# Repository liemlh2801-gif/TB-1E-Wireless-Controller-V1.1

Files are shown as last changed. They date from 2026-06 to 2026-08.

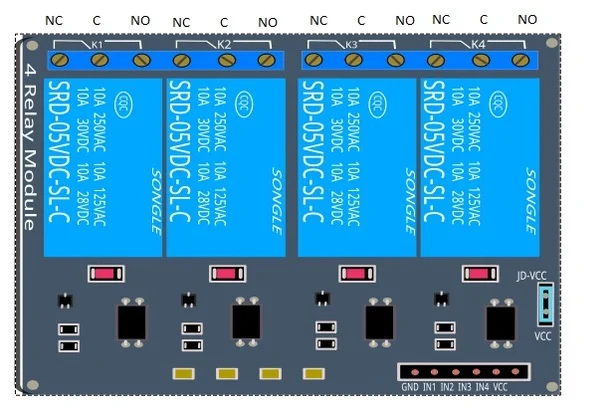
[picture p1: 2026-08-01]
hardware/qelectrotech/elements/Relay-module-for-arduino-616x415.webp

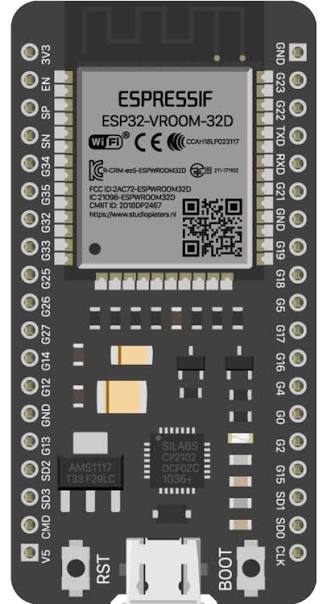
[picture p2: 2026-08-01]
hardware/qelectrotech/elements/images.jpg

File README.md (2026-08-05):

# ESP32 Bluetooth Controller

Android app + **iOS app** + **web app** + ESP32 firmware for controlling a motor/actuator with **UP**, **STOP**, and **DOWN** commands over Bluetooth.

No HC-05 module required — Bluetooth is built into the ESP32.

**Recommended project path (ASCII only, for Gradle/Fritzing on Windows):**

`D:\01 Lam viec\Gia-cong\drawings\safety-belt-tester\APP\arduino-bt-controller`

## Hardware

### Which ESP32 board?

| Board in Arduino IDE | Chip | Bluetooth | App connection |
|---|---|---|---|
| **ESP32 Dev Module** | WROOM-32 | **BLE** (NUS) | Android, **Chrome web**, pair via app/browser |
| **ESP32S3 Dev Module** | S3 | BLE only | Same as WROOM |
| ESP32-C3 / C6 | C3 / C6 | BLE only | Same as S3 |

**Important:** If you see `BluetoothSerial.h: No such file`, you selected **ESP32-S3** (or C3/C6). That is normal — the sketch now uses **BLE** on those boards automatically. Keep your **ESP32S3 Dev Module** board selected and upload again.

### Wiring — ESP32 to L298N

| ESP32 GPIO | L298N / function |
|---|---|
| **3.3V or 5V** | VCC (logic; module power separate) |
| **GND** | GND |
| **GPIO 26** | IN1 |
| **GPIO 27** | IN2 |
| **GPIO 14** | Stop signal |
| **GPIO 25** | BLE connected (idle HIGH; LOW while phone/PC is connected) |
| **GPIO 32** | Manual / Auto mode switch (see below) |
| **GPIO 18** | Top limit switch (see below) |
| **GPIO 19** | Bottom limit switch (see below) |
| **GPIO 33** | ON-HOLD switch (see below) |

| Command | GPIO 26 (IN1) | GPIO 27 (IN2) | GPIO 14 (STOP) |
|---|---|---|---|
| UP | LOW | HIGH | HIGH |
| DOWN | HIGH | LOW | HIGH |
| STOP | HIGH | HIGH | **LOW** |
| RELEASE / idle | HIGH | HIGH | HIGH |

### Manual / Auto mode switch (GPIO 32)

Physical **Manual / Auto** selector on the machine panel. ESP32 reads **GPIO 32** with internal pull-down (Manual is default):

| Switch position | GPIO 32 | Mode | App behavior |
|---|---|---|---|
| **Manual** (default) | **Open** or **GND** | Manual | Momentary — hold LÊN/DỪNG/XUỐNG, release sends `RELEASE` |
| **Auto** | **3.3V only** | Auto | Latch — press/release LÊN or XUỐNG keeps output until DỪNG, opposite direction, or limit |

**Wiring:**

- **Manual:** leave GPIO 32 **open**, or connect to **GND**
- **Auto:** connect GPIO 32 to **3.3V** only (do not use open/float for Auto)

On mode change or BLE connect, ESP32 notifies the app with `MODE: MANUAL` or `MODE: AUTO`.

### App buttons (web / Android / iOS)

App / web buttons match the physical panel (GPIO 21 / 22 / 23). The ESP32 applies the same rules to BLE commands via `maintainAppPanelButtons()` (Manual: hold to run; Auto: latch on press; DỪNG priority). Physical panel inputs take priority if pressed at the same time.

**Manual** (GPIO 32 open or GND):

| Button | Press | Release |
|---|---|---|
| **LÊN** | `UP` — GPIO 26 LOW, GPIO 27/14 HIGH | `RELEASE` — all HIGH |
| **DỪNG** | `STOP` — GPIO 14 LOW | `RELEASE` — all HIGH |
| **XUỐNG** | `DOWN` — GPIO 27 LOW, GPIO 26/14 HIGH | `RELEASE` — all HIGH |

Priority while held: **DỪNG** > **LÊN** > **XUỐNG** (same as panel).

**Auto** (GPIO 32 on 3.3V):

| Button | Press | Release |
|---|---|---|
| **LÊN** | `UP` — GPIO 26 LOW, GPIO 27/14 HIGH | No change — latched |
| **DỪNG** | `STOP` — GPIO 14 LOW | `RELEASE` — all HIGH |
| **XUỐNG** | `DOWN` — GPIO 27 LOW, GPIO 26/14 HIGH | No change — latched |

While **DỪNG** is held, **LÊN** / **XUỐNG** are ignored (same as panel).

### Limit switches (GPIO 18 / GPIO 19)

Two **normally-open** limit switches. ESP32 reads **GPIO 18** (top) and **GPIO 19** (bottom) with internal pull-up:

| Switch | GPIO | Active (limit hit) | Inactive (normal) |
|---|---|---|---|
| **Top limit** | **18** | **LOW** (pin to **GND**) | **Open** or **HIGH** |
| **Bottom limit** | **19** | **LOW** (pin to **GND**) | **Open** or **HIGH** |

**While top limit active:** GPIO 26 set HIGH, then disabled (cannot go LOW); GPIO 27 and GPIO 14 unchanged.

**While bottom limit active:** GPIO 27 set HIGH, then disabled (cannot go LOW); GPIO 26 and GPIO 14 unchanged.

**Wiring (each limit switch):**

- One terminal → **GPIO 18** (top) or **GPIO 19** (bottom)
- Other terminal → **GND**
- Switch closes to GND when the carriage hits the limit (NO switch)

When top limit clears, GPIO 26 is enabled again; if **GPIO 21** is still connected to **GND**, GPIO 26 is allowed to go **LOW**.

When bottom limit clears, GPIO 27 is enabled again; if **GPIO 22** is still connected to **GND**, GPIO 27 is allowed to go **LOW**.

On limit change or BLE connect, ESP32 sends `LIMIT: TOP`, `LIMIT: TOP OFF`, `LIMIT: BOT`, or `LIMIT: BOT OFF`.

### ON-HOLD switch (GPIO 33)

ESP32 reads **GPIO 33** with internal pull-up:

| Switch | GPIO 33 | Effect |
|---|---|---|
| **ON-HOLD active** | **LOW** (pin to **GND**) | **UP input and output stay enabled**; AUTO-DOWN latch cleared |
| **Inactive** | **Open** or **HIGH** | Normal operation |
| **ON-HOLD release** (active→inactive) | LOW→open | If ON-HOLD stays **inactive for 3 seconds**: GPIO 26 inactive (HIGH), GPIO 27 **GND** (LOW), GPIO 14 inactive (HIGH) — same as panel XUỐNG press-release once in Auto (if GPIO 4 enabled). Count resets if ON-HOLD goes active again. |

**Wiring:** one terminal → **GPIO 33**, other → **GND** (closes to GND when hold is engaged).

Panel **LÊN** (GPIO 21), app **UP**, and GPIO 26 output are **never disabled** while ON-HOLD is active.

Device advertises as **TB-1E** when powered on.

## Protocol

Commands are newline-terminated ASCII strings:

| Button | Sent |
|---|---|
| UP | `UP` |
| STOP | `STOP` |
| DOWN | `DOWN` |

Mode notifications from ESP32:

| Message | Meaning |
|---|---|
| `MODE: MANUAL` | Manual mode — momentary buttons |
| `MODE: AUTO` | Auto mode — UP/DOWN latch after release |
| `LIMIT: TOP` / `LIMIT: TOP OFF` | Top limit active / cleared |
| `LIMIT: BOT` / `LIMIT: BOT OFF` | Bottom limit active / cleared |

ESP32 replies with `STATUS: UP`, `STATUS: DOWN`, or `STATUS: STOP`.

## Setup

### 1. ESP32 firmware

1. Install [ESP32 board support](https://docs.espressif.com/projects/arduino-esp32/en/latest/installing.html) in Arduino IDE.
2. Open `esp32/bt_controller/bt_controller.ino`.
3. Select the board that matches your hardware:
   - **ESP32 Dev Module** — original ESP32 (WROOM-32)
   - **ESP32S3 Dev Module** — ESP32-S3 (most common new boards)
4. Select the correct **COM port** (CP2102 / CH340 USB driver if needed).
5. Upload the sketch.
6. Serial Monitor **115200 baud** — you should see:
   - `Bluetooth: BLE UART (TB-1E)`
   - `Bluetooth name: TB-1E`

### 2. Android app (v1.3+)

1. Install **app-debug.apk** (yellow bar shows **v1.3**).
2. Grant **Bluetooth** and **Location** permissions.
3. Power on ESP32.
4. In app **⋮** menu → **refresh** (waits ~5 s for BLE scan).
5. Select **TB-1E** → **KẾT NỐI MÁY THỬ DÂY AN TOÀN**.
6. Use **LÊN**, **DỪNG**, **XUỐNG**.

**WROOM-32 / S3:** connect from the app or Chrome — do not rely on Windows Settings pairing alone.

### 3. iOS app (v1.0)

Requires **ESP32 BLE** firmware (WROOM-32 or S3/C3/C6).

1. On a Mac, open `ios/TB1EController.xcodeproj` in Xcode.
2. Set your **Signing Team** and run on your iPhone.
3. See [ios/README.md](ios/README.md) for full steps.

### 4. Web app (Chrome PC + Chrome Android)

Browser controller in `web/` — no install, **Web Bluetooth** (same protocol as Android app).

1. ESP32 with BLE firmware (WROOM-32 or S3/C3/C6), name **TB-1E**
2. Open **GitHub Pages** URL in **Chrome or Edge on PC**, or Chrome on Android — see [web/README.md](web/README.md)
3. **KẾT NỐI** → hold **LÊN / DỪNG / XUỐNG** (mouse/touch) or **↑ ↓ Space** on PC keyboard

**Safari iPhone:** Web Bluetooth not supported — use the iOS app instead.

### 5. Compile errors

| Error | Cause | Fix |
|---|---|-----|
| `BluetoothSerial.h: No such file` | Old sketch on S3 board | Use latest sketch — it switches to BLE on S3 |
| `#error Select original ESP32` | Old sketch | Update sketch from this repo |
| Upload fails | USB driver / boot mode | Hold **BOOT** during upload; install CP2102/CH340 driver |

## Troubleshooting

| Problem | Fix |
|---|-----|
| **TB-1E** not in app menu | Power ESP32; tap **refresh** in app (BLE scan ~5 s) |
| App connect fails (WROOM-32) | Settings → **TB-1E** → **Disconnect**; connect only from app |
| App connect fails (S3) | Install app **v1.3+**; refresh; select scanned **TB-1E** |
| Motor not moving | Check GPIO 26/27/14 wiring to L298N |

## Project structure

```
arduino-bt-controller/
├── android/          # Kotlin app (Classic BT + BLE)
├── ios/              # SwiftUI iPhone app (BLE only)
├── web/              # Browser app (Web Bluetooth, Chrome Android)
├── esp32/            # ESP32 firmware
├── arduino/          # Legacy note (Nano + HC-05 removed)
└── README.md
```

## Safety

- App sends **RELEASE** on button release, disconnect, and when paused.
- ESP32 sets all GPIO **HIGH** when no app is connected.

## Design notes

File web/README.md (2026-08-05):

# TB-1E Web Controller

Browser version of the TB-1E controller. Same UI and protocol as the Android app.

Works over **Web Bluetooth (BLE)** — connect to ESP32 **TB-1E**. Button behavior matches the physical panel (Manual / Auto).

## Browser support

| Browser | Works? | Notes |
|---|---|---|
| **Chrome on PC (Windows/macOS/Linux)** | **Yes** | Same as Android app — connect **TB-1E**, mouse or keyboard |
| **Edge on PC** | **Yes** | Web Bluetooth supported |
| **Chrome on Android** | **Yes** | Touch controls |
| **Safari on iPhone** | **No** | Use iOS app or Bluefy |
| Firefox | No | Use Chrome or Edge |

**PC (Chrome):** open the GitHub Pages URL → **KẾT NỐI** → pick **TB-1E**. Hold **LÊN / DỪNG / XUỐNG** with mouse, or keys **↑ ↓ Space** (release sends `RELEASE`).

**Hardware:** ESP32-WROOM-32 or ESP32-S3/C3/C6 with BLE firmware.

## Deploy on GitHub Pages (PC Chrome or phone)

After pushing to `main`:

1. Repo → **Settings** → **Pages** → Source: **GitHub Actions**
2. Push triggers `.github/workflows/deploy-web.yml`
3. Open the Pages URL (HTTPS), e.g.:

   `https://liemlh2801-gif.github.io/TB-1E-Wireless-Controller-V1.1/`

4. **PC:** Chrome or Edge → **KẾT NỐI** → **TB-1E** → use buttons or **↑ ↓ Space**
5. **Android:** Chrome → **KẾT NỐI** → hold touch buttons

Safari on iPhone cannot use Web Bluetooth — use the iOS app.

## HTTPS required

Web Bluetooth only runs on **secure pages** (`https://` or `http://localhost`).

Opening `http://192.168.x.x:8080` from your phone **will not work**.

### Option A — PC Chrome (GitHub Pages or localhost)

1. Deploy `web/` to GitHub Pages (HTTPS), or run locally:

```powershell
cd web
npx --yes serve -l 3000
```

2. Open **`http://localhost:3000`** in **Chrome** or **Edge** on the same PC.
3. Turn on **Bluetooth** (Windows Settings → Bluetooth).
4. Power on ESP32 **TB-1E** (BLE firmware).
5. Click **KẾT NỐI MÁY THỬ DÂY AN TOÀN** → select **TB-1E**.
6. Control: click/hold **LÊN / DỪNG / XUỐNG**, or keyboard **↑ ↓ Space** (release = `RELEASE`).

### Option B — Quick UI test on PC (no BLE over plain HTTP)

```bash
cd web
npx --yes serve -l 3000
```

Open `http://localhost:3000` — UI only; Web Bluetooth needs **HTTPS** or **localhost** (localhost works in Chrome on PC).

### Option C — Phone on same Wi‑Fi (HTTPS)

1. Install [mkcert](https://github.com/FiloSottile/mkcert) (once).
2. From the `web` folder run:

```powershell
.\serve-https.ps1
```

3. On your phone (Chrome), open `https://<your-PC-IP>:8443`
4. Accept the certificate warning (self-signed).
5. Tap **KẾT NỐI** → choose **TB-1E**.

### Option D — Deploy to HTTPS hosting

Upload the `web/` folder to any static host with HTTPS (GitHub Pages, Netlify, etc.) and open the URL on your phone.

## Panel image

If the machine image is missing:

```bash
cp ../android/app/src/main/res/drawable/asset1.jpg web/assets/asset1.jpg
```

## Protocol

App / web buttons match the physical panel in **Manual** and **Auto** mode (including DỪNG priority over LÊN / XUỐNG).

**Manual:** `UP` / `DOWN` / `STOP` on press, `RELEASE` on release.

**Auto:**

| Button | Press | Release |
|---|---|---|
| LÊN | `UP` — GPIO 26 LOW | No command |
| DỪNG | `STOP` — GPIO 14 LOW | `RELEASE` — all HIGH |
| XUỐNG | `DOWN` — GPIO 27 LOW | No command |

ESP32 sends `MODE: MANUAL` or `MODE: AUTO` on connect and when the physical mode switch changes.

BLE service: Nordic UART `6E400001-B5A3-F393-E0A9-E50E24DCCA9E`

## Files

```
web/
├── index.html
├── manifest.json
├── css/styles.css
├── js/bluetooth.js
├── js/app.js
├── assets/asset1.jpg
├── serve-https.ps1
└── README.md
```

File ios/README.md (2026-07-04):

# TB-1E Controller — iOS

SwiftUI iPhone app for controlling the **MAY THU DAY AN TOAN (TB-1E)** machine over **Bluetooth LE**.

Matches the Android app: **LÊN / DỪNG / XUỐNG** momentary buttons, connect to **TB-1E**, same command protocol (`UP`, `STOP`, `DOWN`, `RELEASE`).

## Important: iOS and Bluetooth type

| Platform | Classic Bluetooth (ESP32-WROOM SPP) | BLE (ESP32-S3 / C3 / C6) |
|---|---|---|
| Android  | Yes | Yes |
| **iOS**  | **No** (Apple restriction) | **Yes** |

Use **ESP32-S3** firmware from `esp32/bt_controller/bt_controller.ino` with board **ESP32S3 Dev Module**.

## Requirements

- Mac with **Xcode 15+**
- iPhone with **iOS 16+**
- Apple Developer account (free tier works for device testing)
- ESP32-S3 running TB-1E BLE firmware

## Setup in Xcode

1. Open `ios/TB1EController.xcodeproj` in Xcode.
2. Target **TB1EController** → **Signing & Capabilities** → select your **Team**.
3. Connect iPhone → **Run** (▶).
4. Allow **Bluetooth** when prompted.

### Machine panel image

If the machine image is missing:

```bash
cp android/app/src/main/res/drawable/asset1.jpg \
   ios/TB1EController/Assets.xcassets/asset1.imageset/asset1.jpg
```

## Using the app

1. Power on ESP32 (**TB-1E**).
2. Tap **⋯** → **Refresh devices** (~5 s scan).
3. Select **TB-1E**.
4. Tap **KẾT NỐI MÁY THỬ DÂY AN TOÀN**.
5. **Hold** **LÊN / DỪNG / XUỐNG** — release sends `RELEASE`.

## Protocol

| Action | Command |
|---|---|
| LÊN pressed | `UP` |
| XUỐNG pressed  | `DOWN` |
| DỪNG pressed | `STOP` |
| Button release | `RELEASE` |

ESP32 sends `MODE: MANUAL` or `MODE: AUTO` from the physical mode switch (GPIO 32). In **Auto** mode, wireless buttons are disabled.

BLE: Nordic UART `6E400001-B5A3-F393-E0A9-E50E24DCCA9E`

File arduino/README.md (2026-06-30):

# Legacy Arduino Nano + HC-05

This project now uses **ESP32** built-in Bluetooth instead of Arduino Nano + HC-05.

Use the firmware in [`../esp32/bt_controller/`](../esp32/bt_controller/).

The old `bt_controller.ino` for Nano/HC-05 has been removed.

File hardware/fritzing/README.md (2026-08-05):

# TB-1E — Fritzing wiring (ESP32 38-pin + CW-022)

Realistic breadboard wiring diagram for **TB-1E** using **Fritzing 0.9.3** at:

```
E:\fritzing.0.9.3b.64.pc\Fritzing.exe
```

## ESP32 part (import first)

This sketch uses the **ESP32 DevKitc V4** part from your **Mine** parts bin (not the broken embedded TB1E part).

1. In Fritzing: **File → Open** → `C:\Users\Admin\Downloads\ESP32 DevKitc V4.fzpz`  
   (or **Mine → Import** if already imported once)
2. Then open the wiring sketch via `open_in_fritzing.bat`

| Wire | ESP32 DevKitc V4 pin | CW-022 |
|---|---|---|
| Red | **5V** | VCC |
| Black | **GND** | GND |
| Blue | **IO26** | IN1 |
| Blue | **IO27** | IN2 |
| Green | **IO14** | IN3 |

> **Note:** You imported `ESP32 DevKitc V4.fzpz` (in Downloads), not `ESP32-38PinWide-fixed.fzpz` from the Fritzing forum. Both are 38-pin ESP32 boards; DevKitc V4 has a photo-realistic breadboard view and is valid for TB-1E wiring.

## Quick start

1. **Generate** (if `TB-1E_ESP32_CW022_Wiring.fzz` is missing):
   ```
   python hardware/fritzing/generate_tb1e_fritzing.py
   ```

2. **Open** — double-click:
   ```
   hardware/fritzing/open_in_fritzing.bat
   ```
   Or in Fritzing: **File → Open** → `C:\TB1E_Fritzing\TB-1E_ESP32_CW022_Wiring.fzz`

   **Important:** Fritzing 0.9.3 on Windows cannot open `.fzz` files from paths with Vietnamese/Unicode characters. Keep the project under ASCII-only folders:

   `D:\01 Lam viec\Gia-cong\drawings\safety-belt-tester\APP\arduino-bt-controller`

   Or use the batch file / copy under `C:\TB1E_Fritzing\`.

3. Switch to **Breadboard** view for the physical wiring layout.

## What's in the sketch

| Part | Pins shown |
|---|---|
| **ESP32 DevKitc V4** | Imported user part — 38 pins (IO26, IO27, IO14, 5V, GND, …) |
| **CW-022 4CH relay** | GND, IN1, IN2, IN3, IN4, VCC |

### Pre-wired (motor outputs)

| Wire color | ESP32 | CW-022 | Function |
|---|---|---|---|
| Red | 5V | VCC | 5V power |
| Black | GND | GND | Ground |
| Blue | IO26 | IN1 | Motor IN1 (LÊN) |
| Blue | IO27 | IN2 | Motor IN2 (XUỐNG) |
| Green | IO14 | IN3 | STOP (DỪNG) |
| — | — | IN4 | Spare |

**CW-022 is active LOW:** GPIO HIGH = relay off, GPIO LOW = relay on.

## Add panel wiring in Fritzing

Drag wires from these ESP32 pins to switches/buttons (switch other terminal → **GND**):

| GPIO | Function |
|---|---|
| 32 | Manual / Auto |
| 18 | Top limit |
| 19 | Bottom limit |
| 25 | ON-HOLD |
| 21 | Panel LÊN |
| 22 | Panel XUỐNG |
| 23 | Panel DỪNG |
| 4 | AUTO-DOWN |
| 33 | BLE connected output (LOW = connected) |

## Custom parts

- `parts/TB1E_CW022_4ch/` — CW-022 4-channel relay (embedded in `.fzz`)
- ESP32: use imported **ESP32 DevKitc V4** (see above). Legacy `TB1E_ESP32_38pin/` is no longer used by the sketch.

## Optional: ESP32-38PinWide-fixed (forum)

If you prefer Peter van Epp's forum part instead of DevKitc V4, download `ESP32-38PinWide-fixed.fzpz` from the [Fritzing forum](https://forum.fritzing.org/t/esp32-wroom-32u/12978), import it, then reconnect wires manually in the sketch.

## Regenerate

```
python hardware/fritzing/generate_tb1e_fritzing.py
```

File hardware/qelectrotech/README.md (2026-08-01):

# TB-1E — ESP32 ↔ CW-022 Wiring (QElectroTech)

Wiring sketch for **ESP32 Dev Module** connected to **CW-022** 2-channel 5V relay modules, for the TB-1E wireless controller firmware.

## Open in QElectroTech

1. Install [QElectroTech](https://qelectrotech.org/) (0.8 or newer recommended).
2. Open file:
   ```
   hardware/qelectrotech/TB-1E_ESP32_CW022_Wiring.qet
   ```
3. Three folios (tabs):
   - **F1 — ESP32 to CW-022 Control** — main control wiring
   - **F2 — CW-022 Relay Outputs** — relay contacts to machine
   - **F3 — Panel Inputs Reference** — switches and buttons

Custom symbols are embedded in the project (`tb1e` collection). Standalone copies are in `elements/`.

## CW-022 module

Standard **2-channel 5V opto-isolated relay board** (often labeled CW-022 / 2CH relay):

| Pin | Connect to |
|-----|---|
| **VCC** | ESP32 **5V** (VIN / USB 5V) |
| **GND** | ESP32 **GND** (common ground) |
| **IN1** | ESP32 GPIO (see table) |
| **IN2** | ESP32 GPIO (see table) |
| **JD-VCC** | Jumper **ON** (default) — shares 5V with VCC |

**Trigger:** Active **LOW** — GPIO **LOW** = relay ON, GPIO **HIGH** = relay OFF.

TB-1E firmware needs **3 relay channels** → use **2× CW-022** modules.

## Control wiring (Folio 1)

| ESP32 | CW-022 module | Channel | Function |
|---|---|---|---|
| **5V** | #1 VCC, #2 VCC | — | Logic + coil power |
| **GND** | #1 GND, #2 GND | — | Common ground |
| **GPIO 26** | #1 **IN1** | R1 | Motor IN1 (LÊN) |
| **GPIO 27** | #1 **IN2** | R2 | Motor IN2 (XUỐNG) |
| **GPIO 14** | #2 **IN1** | R1 | Motor STOP (DỪNG) |
| — | #2 IN2 | R2 | Spare |

## Relay outputs (Folio 2)

Wire **NO** (normally open) contacts unless your machine needs NC:

| Relay | COM | NO → |
|---|-----|---|
| CW-022 #1 R1 | Machine IN1 common | IN1 active (LÊN) |
| CW-022 #1 R2 | Machine IN2 common | IN2 active (XUỐNG) |
| CW-022 #2 R1 | Machine STOP common | STOP active (DỪNG) |

## Power notes

- Use **5V / ≥1A** supply when both relay modules may energize together (~70 mA per channel).
- Keep **GND** shared between ESP32 and all CW-022 boards.
- For full opto-isolation: remove JD-VCC jumper and feed JD-VCC from a separate 5V supply (GND still common).

## Signal table (firmware)

| Command | GPIO 26 | GPIO 27 | GPIO 14 |
|---|---|---|---|
| LÊN (UP) | LOW | HIGH | HIGH |
| XUỐNG (DOWN) | HIGH | LOW | HIGH |
| DỪNG (STOP) | HIGH | HIGH | **LOW** |
| Idle | HIGH | HIGH | HIGH |

## ASCII overview

```
                    ┌─────────────────┐
    USB 5V ────────►│  ESP32 Dev Kit  │
                    │                 │
         GPIO26 ───►│ IO26 ───────────┼──► CW-022 #1 IN1 ──► R1 → IN1 (LÊN)
         GPIO27 ───►│ IO27 ───────────┼──► CW-022 #1 IN2 ──► R2 → IN2 (XUỐNG)
         GPIO14 ───►│ IO14 ───────────┼──► CW-022 #2 IN1 ──► R1 → STOP
                    │ 5V  ────────────┼──► VCC (both modules)
                    │ GND ────────────┼──► GND (both modules)
                    └─────────────────┘
```

## Edit symbols

To change symbols: **Projet → Collection embarquée → tb1e**, or edit files in `elements/` and re-import.

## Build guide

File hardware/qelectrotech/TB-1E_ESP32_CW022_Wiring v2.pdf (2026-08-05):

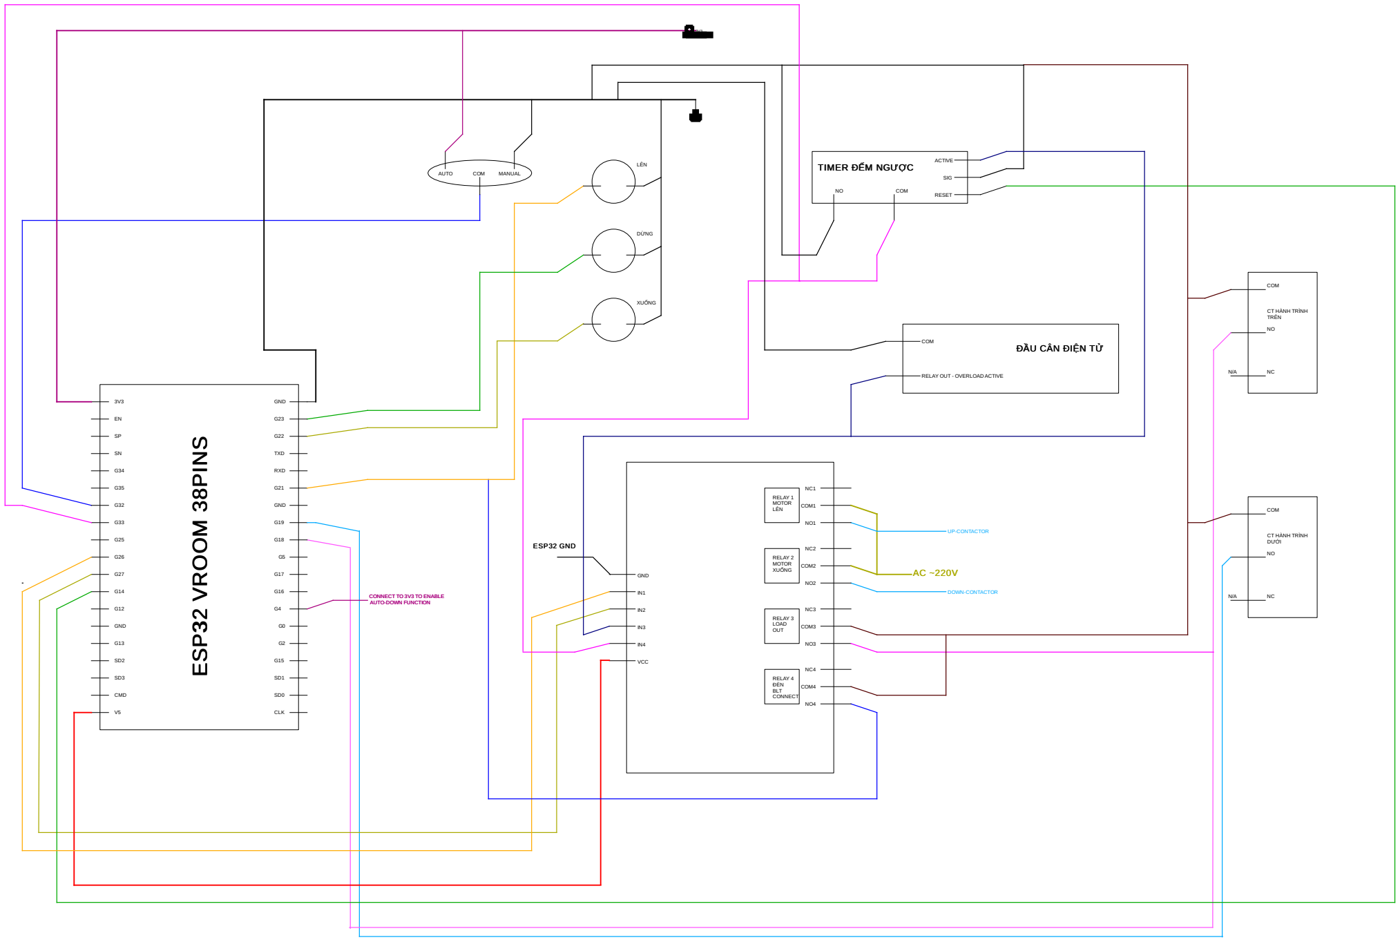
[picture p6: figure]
RÌN; TIM; ESP32 VROOM 38P NI S ESP32 VROOM 38PINS

ỚI SP | NC NC3 | NO | COM AUTO | AC ~220V COM | DOWN-CONTACTOR UP-CONTACTOR NO4 | COM G35 G34 G25 G33 V53V3 | NO1 G13 G32 | SIG | NO G18G0 G4 G15 TXD | NO2 G17 | RELAY 1 MOTOR LÊN | NC2 IN2 G23 | RELAY 3 LOAD OUT SD1 CLK | RESET ACTIVE IN3 GND G14 | ĐẦU CÂN ĐIỆN TỬ | COM N/A ESP32 GND | RELAY OUT - OVERLOAD ACTIVE NC4 COM3 | NO G26 GND | CONNECT TO 3V3 TO ENABLE AUTO-DOWN FUNCTION G12 | CT HÀ

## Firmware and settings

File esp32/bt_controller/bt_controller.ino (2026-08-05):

/*

 * Bluetooth motor controller for MAY THU DAY AN TOAN (TB-1E).

 *

 * Supported boards (Arduino IDE):

 *   ESP32 Dev Module      — ESP32-WROOM-32

 *   ESP32S3 / C3 / C6     — BLE-only chips

 *

 * All boards use BLE Nordic UART Service (Chrome web, Android, iOS).

 * Phone/PC sees Bluetooth name TB-1E.

 *

 * GPIO 32 mode: INPUT_PULLDOWN — Manual=open/GND, Auto=3.3V only.

 * GPIO 18 top limit: while active GPIO26 disabled; GPIO 19 bottom limit: while active GPIO27 disabled.
 * GPIO 33 ON-HOLD: active=LOW/GND; after active→inactive, if inactive 3s → DOWN (GPIO26 inactive, GPIO27 GND, GPIO14 inactive).
 * While ON-HOLD active, UP input (GPIO21/app) and UP output (GPIO26) are never disabled.
 * AUTO-DOWN output: GPIO26 HIGH, GPIO27 LOW, GPIO14 HIGH until button or bottom limit.
 * GPIO 21/22/23 panel LÊN/XUỐNG/DỪNG: LOW to GND = pressed (INPUT_PULLUP).
 * Panel inputs are always polled — never disabled.
 * STOP (panel GPIO23 / app) input and output are never disabled.

 */



#include <Arduino.h>



const int IN1 = 26;

const int IN2 = 27;

const int STOP_PIN = 14;

const int BT_CONNECTED_PIN = 25;  // idle HIGH; LOW while phone/PC is connected via BLE

const int MODE_SWITCH_PIN = 32;   // INPUT_PULLDOWN: open/GND=Manual (default), 3.3V=Auto

const int TOP_LIMIT_PIN = 18;     // INPUT_PULLUP: LOW to GND=active, open/HIGH=inactive

const int BOT_LIMIT_PIN = 19;     // INPUT_PULLUP: LOW to GND=active, open/HIGH=inactive

const int AUTO_DOWN_PIN = 4;      // INPUT_PULLDOWN: 3.3V=enabled, open/GND=inactive

const int ON_HOLD_PIN = 33;       // INPUT_PULLUP: LOW=active (to GND); release=open (HIGH) latches AUTO-DOWN

const int PANEL_UP_PIN = 21;      // INPUT_PULLUP: LOW to GND = LÊN pressed

const int PANEL_DOWN_PIN = 22;    // INPUT_PULLUP: LOW to GND = XUỐNG pressed

const int PANEL_STOP_PIN = 23;    // INPUT_PULLUP: LOW to GND = DỪNG pressed

const char BT_DEVICE_NAME[] = "TB-1E";

const long USB_BAUD = 115200;

const unsigned long INPUT_DEBOUNCE_MS = 50;

const unsigned long PANEL_DEBOUNCE_MS = 10;

const unsigned long AUTO_DOWN_FIRST_START_DELAY_MS = 3000;



bool modeSwitchAuto = false;

bool modeSwitchLastReading = false;

unsigned long modeSwitchLastChangeMs = 0;



bool topLimitActive = false;

bool botLimitActive = false;

bool topLimitLastReading = false;

bool botLimitLastReading = false;

unsigned long topLimitLastChangeMs = 0;

unsigned long botLimitLastChangeMs = 0;

enum PanelEdge { PANEL_EDGE_NONE, PANEL_EDGE_RISE, PANEL_EDGE_FALL };

struct PanelButtonState {

  bool stable;

  bool lastRaw;

  unsigned long lastChangeMs;

};

bool autoDownFirstStartPending = true;

unsigned long autoDownFirstStartAt = 0;

bool autoDownOnHoldInactiveArmed = false;

unsigned long autoDownOnHoldInactiveSince = 0;

bool autoDownOnHoldInactiveFired = false;

bool autoDownLatched = false;

PanelButtonState onHoldInput = {false, false, 0};

PanelButtonState panelUp = {false, false, 0};

PanelButtonState panelDown = {false, false, 0};

PanelButtonState panelStop = {false, false, 0};

bool appUpHeld = false;

bool appDownHeld = false;

bool appStopHeld = false;



void logUsb(const char* line);

void setAllHigh();

void writeIn1(bool levelHigh);

void writeIn2(bool levelHigh);

void setBtConnectedOutput(bool connected);

void onAppDisconnected();

void moveUp();

void moveDown();

void stopPressed();

void stopReleased();

void handleCommand(const String& cmd);

bool isAppConnected();

bool isAutoMode();

bool isTopLimitActive();

bool isBotLimitActive();

void sendModeStatus();

void sendLimitStatus();

void sendHoldStatus();

void pollModeSwitch();

void pollLimitSwitches();

void scheduleAutoDownFirstStart();

void pollAutoDownFirstStart();

void resetAutoDownOnHoldInactiveTimer();

void armAutoDownOnHoldInactiveTimer();

void pollAutoDownOnHoldInactive();

void pollOnHold();

void activateAutoDown();

void clearAutoDownLatch();

void maintainAutoDownLatch();

bool isAutoDownEnabled();

bool isStopOutputActive();

bool isPanelStopPressed();

void setupPanelInputs();

bool readPanelPressed(int pin);

void initPanelButtons();

PanelEdge pollPanelEdge(PanelButtonState& btn, int pin);

void pollPanelButtons();

void clearAppButtonState();

bool isPanelActive();

void applyAppPanelOutputs();

void maintainAppPanelButtons();

void enforceLimitOutputs();



#if CONFIG_IDF_TARGET_ESP32 || CONFIG_IDF_TARGET_ESP32S3 || CONFIG_IDF_TARGET_ESP32C3 || CONFIG_IDF_TARGET_ESP32C6



#include <BLEDevice.h>

#include <BLEServer.h>

#include <BLEUtils.h>

#include <BLE2902.h>



#define NUS_SERVICE_UUID "6E400001-B5A3-F393-E0A9-E50E24DCCA9E"

#define NUS_RX_UUID "6E400002-B5A3-F393-E0A9-E50E24DCCA9E"

#define NUS_TX_UUID "6E400003-B5A3-F393-E0A9-E50E24DCCA9E"



BLEServer* bleServer = nullptr;

BLECharacteristic* bleTxChar = nullptr;

bool bleClientConnected = false;

bool blePendingAdvertRestart = false;

unsigned long bleAdvertRestartAt = 0;



void scheduleBleAdvertRestart() {

  blePendingAdvertRestart = true;

  bleAdvertRestartAt = millis() + 500;

}



void pollBleAdvertising() {

  if (blePendingAdvertRestart && millis() >= bleAdvertRestartAt) {

    blePendingAdvertRestart = false;

    BLEDevice::startAdvertising();

    logUsb("BLE advertising restarted");

  }

}



void sendBtReply(const char* msg) {

  if (bleClientConnected && bleTxChar != nullptr) {

    bleTxChar->setValue(msg);

    bleTxChar->notify();

  }

}



class BleServerCallbacks : public BLEServerCallbacks {

  void onConnect(BLEServer* server) override {

    bleClientConnected = true;

    setBtConnectedOutput(true);

    logUsb("BLE client connected");

    sendModeStatus();

    sendLimitStatus();

    sendHoldStatus();

  }



  void onDisconnect(BLEServer* server) override {

    bleClientConnected = false;

    setBtConnectedOutput(false);

    onAppDisconnected();

    logUsb("BLE client disconnected");

    scheduleBleAdvertRestart();

  }

};



class BleRxCallbacks : public BLECharacteristicCallbacks {

  void onWrite(BLECharacteristic* characteristic) override {

    String cmd = String(characteristic->getValue().c_str());

    cmd.trim();

    if (cmd.length() > 0) {

      handleCommand(cmd);

    }

  }

};



bool beginBluetooth() {

  BLEDevice::init(BT_DEVICE_NAME);

  BLEDevice::setMTU(517);



  bleServer = BLEDevice::createServer();

  bleServer->setCallbacks(new BleServerCallbacks());



  BLEService* service = bleServer->createService(NUS_SERVICE_UUID);



  bleTxChar = service->createCharacteristic(

    NUS_TX_UUID,

    BLECharacteristic::PROPERTY_NOTIFY

  );

  bleTxChar->addDescriptor(new BLE2902());



  BLECharacteristic* rxChar = service->createCharacteristic(

    NUS_RX_UUID,

    BLECharacteristic::PROPERTY_WRITE | BLECharacteristic::PROPERTY_WRITE_NR

  );

  rxChar->setCallbacks(new BleRxCallbacks());



  service->start();



  BLEAdvertisementData advertisementData;

  advertisementData.setFlags(0x06);

  advertisementData.setName(BT_DEVICE_NAME);

  advertisementData.setCompleteServices(BLEUUID(NUS_SERVICE_UUID));



  BLEAdvertisementData scanResponseData;

  scanResponseData.setName(BT_DEVICE_NAME);

  scanResponseData.setCompleteServices(BLEUUID(NUS_SERVICE_UUID));



  BLEAdvertising* advertising = BLEDevice::getAdvertising();

  advertising->setAdvertisementData(advertisementData);

  advertising->setScanResponseData(scanResponseData);

  advertising->start();

  return true;

}



bool bluetoothHasCommand() {

  return false;

}



String readBluetoothCommand() {

  return String();

}



void logBtMode() {

  Serial.println("Bluetooth: BLE UART (TB-1E)");

}



bool isAppConnected() {

  return bleClientConnected;

}



#else



#error Unsupported board. Use ESP32 Dev Module (WROOM-32) or ESP32-S3/C3/C6.



#endif



void logUsb(const char* line) {

  Serial.println(line);

}



void setAllHigh() {

  digitalWrite(IN1, HIGH);

  digitalWrite(IN2, HIGH);

  digitalWrite(STOP_PIN, HIGH);

}



void writeIn1(bool levelHigh) {

  if (!levelHigh && topLimitActive) {

    digitalWrite(IN1, HIGH);

    return;

  }

  digitalWrite(IN1, levelHigh ? HIGH : LOW);

}



void writeIn2(bool levelHigh) {

  if (!levelHigh && botLimitActive) {

    digitalWrite(IN2, HIGH);

    return;

  }

  digitalWrite(IN2, levelHigh ? HIGH : LOW);

}



void setBtConnectedOutput(bool connected) {

  digitalWrite(BT_CONNECTED_PIN, connected ? LOW : HIGH);

}



void onAppDisconnected() {

  clearAppButtonState();

  clearAutoDownLatch();

  setAllHigh();

  logUsb("No app connection — GPIO26/27/14 HIGH");

}



void stopPressed() {

  digitalWrite(IN1, HIGH);

  digitalWrite(IN2, HIGH);

  digitalWrite(STOP_PIN, LOW);

}



void stopReleased() {

  digitalWrite(IN1, HIGH);

  digitalWrite(IN2, HIGH);

  digitalWrite(STOP_PIN, HIGH);

}



void moveUp() {

  writeIn1(LOW);

  writeIn2(HIGH);

  digitalWrite(STOP_PIN, HIGH);

}



void moveDown() {

  writeIn1(HIGH);

  writeIn2(LOW);

  digitalWrite(STOP_PIN, HIGH);

}



bool isAutoMode() {

  return modeSwitchAuto;

}



bool readModeSwitchRaw() {

  return digitalRead(MODE_SWITCH_PIN) == HIGH;

}



bool readTopLimitRaw() {

  return digitalRead(TOP_LIMIT_PIN) == LOW;

}



bool readBotLimitRaw() {

  return digitalRead(BOT_LIMIT_PIN) == LOW;

}



bool readOnHoldPressed() {

  return digitalRead(ON_HOLD_PIN) == LOW;

}



bool isOnHoldActive() {

  return readOnHoldPressed();

}



bool isAutoDownEnabled() {

  return digitalRead(AUTO_DOWN_PIN) == HIGH;

}



bool isStopOutputActive() {

  return digitalRead(STOP_PIN) == LOW;

}



bool isPanelStopPressed() {

  return digitalRead(PANEL_STOP_PIN) == LOW;

}



bool isTopLimitActive() {

  return topLimitActive;

}



bool isBotLimitActive() {

  return botLimitActive;

}



bool isMovingUp() {

  return digitalRead(IN1) == LOW &&

         digitalRead(IN2) == HIGH &&

         digitalRead(STOP_PIN) == HIGH;

}



bool isMovingDown() {

  return digitalRead(IN1) == HIGH &&

         digitalRead(IN2) == LOW &&

         digitalRead(STOP_PIN) == HIGH;

}



void sendModeStatus() {

  sendBtReply(isAutoMode() ? "MODE: AUTO" : "MODE: MANUAL");

}



void sendLimitStatus() {

  sendBtReply(topLimitActive ? "LIMIT: TOP" : "LIMIT: TOP OFF");

  sendBtReply(botLimitActive ? "LIMIT: BOT" : "LIMIT: BOT OFF");

}



void sendHoldStatus() {

  sendBtReply(readOnHoldPressed() ? "HOLD: ON" : "HOLD: OFF");

}



void clearAutoDownLatch() {

  if (autoDownLatched) {

    autoDownLatched = false;

    logUsb("AUTO-DOWN latch cleared");

  }

}



void activateAutoDown() {

  if (!isAutoMode()) {

    return;

  }

  if (!isAutoDownEnabled()) {

    logUsb("AUTO-DOWN skipped — GPIO4 not on 3.3V");

    return;

  }

  if (isBotLimitActive()) {

    logUsb("AUTO-DOWN skipped — bottom limit active");

    return;

  }

  autoDownLatched = true;

  moveDown();

  logUsb("AUTO-DOWN latched — GPIO26 HIGH, GPIO27 LOW, GPIO14 HIGH");

}



void maintainAutoDownLatch() {

  if (!autoDownLatched) {

    return;

  }

  if (isOnHoldActive()) {

    return;

  }

  if (isPanelStopPressed() || isStopOutputActive()) {

    return;

  }

  if (botLimitActive) {

    clearAutoDownLatch();

    return;

  }

  moveDown();

}



void scheduleAutoDownFirstStart() {

  if (!isAutoMode() || !isAutoDownEnabled()) {

    autoDownFirstStartPending = false;

    return;

  }

  if (readOnHoldPressed()) {

    autoDownFirstStartPending = false;

    logUsb("AUTO-DOWN first start skipped — ON-HOLD active (GPIO33 LOW) at boot");

    return;

  }

  autoDownFirstStartAt = millis() + AUTO_DOWN_FIRST_START_DELAY_MS;

  logUsb("AUTO-DOWN first start scheduled — DOWN in 3 seconds");

}



void resetAutoDownOnHoldInactiveTimer() {

  if (autoDownOnHoldInactiveArmed && !autoDownOnHoldInactiveFired) {

    logUsb("AUTO-DOWN ON-HOLD inactive count reset");

  }

  autoDownOnHoldInactiveArmed = false;

  autoDownOnHoldInactiveFired = false;

}



void armAutoDownOnHoldInactiveTimer() {

  if (!isAutoMode()) {

    logUsb("AUTO-DOWN ON-HOLD release ignored — not Auto mode (GPIO32)");

    return;

  }

  if (!isAutoDownEnabled()) {

    logUsb("AUTO-DOWN skipped — GPIO4 not on 3.3V");

    return;

  }

  autoDownOnHoldInactiveArmed = true;

  autoDownOnHoldInactiveSince = millis();

  autoDownOnHoldInactiveFired = false;

  logUsb("ON-HOLD active→inactive — counting 3s inactive for DOWN");

}



void pollAutoDownOnHoldInactive() {

  if (!autoDownOnHoldInactiveArmed || autoDownOnHoldInactiveFired) {

    return;

  }

  if (readOnHoldPressed()) {

    resetAutoDownOnHoldInactiveTimer();

    return;

  }

  if (millis() - autoDownOnHoldInactiveSince < AUTO_DOWN_FIRST_START_DELAY_MS) {

    return;

  }

  autoDownOnHoldInactiveFired = true;

  if (!isAutoMode() || !isAutoDownEnabled()) {

    logUsb("AUTO-DOWN cancelled — not Auto or GPIO4 inactive");

    return;

  }

  if (isBotLimitActive()) {

    logUsb("AUTO-DOWN skipped — bottom limit active");

    return;

  }

  clearAutoDownLatch();

  moveDown();

  logUsb("ON-HOLD inactive 3s — DOWN (GPIO26 inactive, GPIO27 GND, GPIO14 inactive)");

}



void pollAutoDownFirstStart() {

  if (!autoDownFirstStartPending) {

    return;

  }

  if (millis() < autoDownFirstStartAt) {

    return;

  }

  autoDownFirstStartPending = false;

  if (!isAutoMode() || !isAutoDownEnabled()) {

    logUsb("AUTO-DOWN first start cancelled — not Auto or GPIO4 inactive");

    return;

  }

  if (readOnHoldPressed()) {

    logUsb("AUTO-DOWN first start cancelled — ON-HOLD active (GPIO33 LOW)");

    return;

  }

  logUsb("AUTO-DOWN first start — 3s elapsed, DOWN once");

  activateAutoDown();

}



void pollOnHold() {

  // ON-HOLD: LOW/GND = active; open/HIGH = inactive
  // pollPanelEdge: RISE = pressed (active), FALL = released (inactive)

  const PanelEdge holdEdge = pollPanelEdge(onHoldInput, ON_HOLD_PIN);



  if (holdEdge == PANEL_EDGE_RISE) {

    resetAutoDownOnHoldInactiveTimer();

    clearAutoDownLatch();

    sendBtReply("HOLD: ON");

    logUsb("ON-HOLD active (GPIO33 to GND) — UP input/output enabled");

  } else if (holdEdge == PANEL_EDGE_FALL) {

    sendBtReply("HOLD: OFF");

    armAutoDownOnHoldInactiveTimer();

  }

}



void onModeChanged() {

  resetAutoDownOnHoldInactiveTimer();

  clearAutoDownLatch();

  setAllHigh();

  initPanelButtons();

  logUsb(isAutoMode()

    ? "MODE: AUTO — panel UP/DOWN latch until DỪNG; DỪNG momentary"

    : "MODE: MANUAL — panel momentary UP/DOWN/DỪNG");

  sendModeStatus();

}



void onTopLimitChanged() {

  if (topLimitActive) {

    digitalWrite(IN1, HIGH);

    sendBtReply("LIMIT: TOP");

    logUsb("LIMIT TOP — GPIO26 set HIGH, then disabled");

  } else {

    sendBtReply("LIMIT: TOP OFF");

    logUsb("Top limit clear — GPIO26 enabled");

    if (readPanelPressed(PANEL_UP_PIN)) {

      moveUp();

      logUsb("GPIO21 still to GND — GPIO26 allowed LOW");

    }

  }

}



void onBotLimitChanged() {

  if (botLimitActive) {

    clearAutoDownLatch();

    digitalWrite(IN2, HIGH);

    sendBtReply("LIMIT: BOT");

    logUsb("LIMIT BOT — GPIO27 set HIGH, then disabled");

  } else {

    sendBtReply("LIMIT: BOT OFF");

    logUsb("Bottom limit clear — GPIO27 enabled");

    if (readPanelPressed(PANEL_DOWN_PIN)) {

      moveDown();

      logUsb("GPIO22 still to GND — GPIO27 allowed LOW");

    }

  }

}



void pollDebouncedInput(

  bool& active,

  bool& lastReading,

  unsigned long& lastChangeMs,

  bool (*readRaw)(),

  void (*onChanged)()

) {

  const bool reading = readRaw();



  if (reading != lastReading) {

    lastChangeMs = millis();

    lastReading = reading;

  }



  if (millis() - lastChangeMs >= INPUT_DEBOUNCE_MS && reading != active) {

    active = reading;

    onChanged();

  }

}



void pollModeSwitch() {

  pollDebouncedInput(

    modeSwitchAuto,

    modeSwitchLastReading,

    modeSwitchLastChangeMs,

    readModeSwitchRaw,

    onModeChanged

  );

}



void pollLimitSwitches() {

  pollDebouncedInput(

    topLimitActive,

    topLimitLastReading,

    topLimitLastChangeMs,

    readTopLimitRaw,

    onTopLimitChanged

  );

  pollDebouncedInput(

    botLimitActive,

    botLimitLastReading,

    botLimitLastChangeMs,

    readBotLimitRaw,

    onBotLimitChanged

  );

}



void setupAutoDownInputs() {

  pinMode(AUTO_DOWN_PIN, INPUT_PULLDOWN);

  pinMode(ON_HOLD_PIN, INPUT_PULLUP);

  initPanelButton(onHoldInput, ON_HOLD_PIN);

}



bool readPanelPressed(int pin) {

  return digitalRead(pin) == LOW;

}



void setupPanelInputs() {

  pinMode(PANEL_UP_PIN, INPUT_PULLUP);

  pinMode(PANEL_DOWN_PIN, INPUT_PULLUP);

  pinMode(PANEL_STOP_PIN, INPUT_PULLUP);

}



void initPanelButton(PanelButtonState& btn, int pin) {

  const bool raw = readPanelPressed(pin);

  btn.lastRaw = raw;

  btn.stable = raw;

  btn.lastChangeMs = millis();

}



void initPanelButtons() {

  initPanelButton(panelUp, PANEL_UP_PIN);

  initPanelButton(panelDown, PANEL_DOWN_PIN);

  initPanelButton(panelStop, PANEL_STOP_PIN);

}



PanelEdge pollPanelEdge(PanelButtonState& btn, int pin) {

  const bool raw = readPanelPressed(pin);



  if (raw != btn.lastRaw) {

    btn.lastChangeMs = millis();

    btn.lastRaw = raw;

  }



  if (millis() - btn.lastChangeMs < PANEL_DEBOUNCE_MS) {

    return PANEL_EDGE_NONE;

  }



  const bool debounced = btn.lastRaw;

  if (debounced == btn.stable) {

    return PANEL_EDGE_NONE;

  }



  const bool wasStable = btn.stable;

  btn.stable = debounced;



  if (debounced && !wasStable) {

    return PANEL_EDGE_RISE;

  }

  if (!debounced && wasStable) {

    return PANEL_EDGE_FALL;

  }

  return PANEL_EDGE_NONE;

}



void clearAppButtonState() {

  appUpHeld = false;

  appDownHeld = false;

  appStopHeld = false;

}



bool isPanelActive() {

  return panelUp.stable || panelDown.stable || panelStop.stable;

}



void applyAppPanelOutputs() {

  if (!isAppConnected() || isPanelActive()) {

    return;

  }



  if (!isAutoMode()) {

    if (appStopHeld) {

      clearAutoDownLatch();

      stopPressed();

    } else if (appUpHeld) {

      clearAutoDownLatch();

      moveUp();

    } else if (appDownHeld) {

      clearAutoDownLatch();

      moveDown();

    } else if (!autoDownLatched) {

      stopReleased();

    }

    return;

  }



  if (appStopHeld) {

    clearAutoDownLatch();

    stopPressed();

  }

}



void maintainAppPanelButtons() {

  applyAppPanelOutputs();

}



void pollPanelButtons() {

  if (!isAutoMode()) {

    pollPanelEdge(panelUp, PANEL_UP_PIN);

    pollPanelEdge(panelDown, PANEL_DOWN_PIN);

    pollPanelEdge(panelStop, PANEL_STOP_PIN);



    if (panelStop.stable) {

      clearAutoDownLatch();

      stopPressed();

    } else if (panelUp.stable) {

      clearAutoDownLatch();

      moveUp();

    } else if (panelDown.stable) {

      clearAutoDownLatch();

      moveDown();

    } else if (!autoDownLatched) {

      stopReleased();

    }

    return;

  }



  const PanelEdge stopEdge = pollPanelEdge(panelStop, PANEL_STOP_PIN);



  if (panelStop.stable) {

    clearAutoDownLatch();

    stopPressed();

    return;

  }



  if (stopEdge == PANEL_EDGE_FALL) {

    clearAutoDownLatch();

    stopReleased();

    return;

  }



  if (pollPanelEdge(panelUp, PANEL_UP_PIN) == PANEL_EDGE_RISE) {

    clearAutoDownLatch();

    moveUp();

  }

  if (pollPanelEdge(panelDown, PANEL_DOWN_PIN) == PANEL_EDGE_RISE) {

    clearAutoDownLatch();

    moveDown();

  }

}



void enforceLimitOutputs() {

  if (topLimitActive && digitalRead(IN1) == LOW) {

    digitalWrite(IN1, HIGH);

  }

  if (botLimitActive && digitalRead(IN2) == LOW) {

    digitalWrite(IN2, HIGH);

  }

}
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
void loop() {

#if CONFIG_IDF_TARGET_ESP32 || CONFIG_IDF_TARGET_ESP32S3 || CONFIG_IDF_TARGET_ESP32C3 || CONFIG_IDF_TARGET_ESP32C6

  pollBleAdvertising();

#endif



  pollModeSwitch();

  pollLimitSwitches();

  pollOnHold();

  pollAutoDownOnHoldInactive();

  pollAutoDownFirstStart();

  maintainAutoDownLatch();

  pollPanelButtons();

  maintainAppPanelButtons();

  enforceLimitOutputs();



  static bool appWasConnected = false;

  const bool appConnected = isAppConnected();



  if (appWasConnected && !appConnected) {

    onAppDisconnected();

  }

  appWasConnected = appConnected;



  if (bluetoothHasCommand()) {

    handleCommand(readBluetoothCommand());

  }

}

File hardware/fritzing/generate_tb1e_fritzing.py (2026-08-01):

#!/usr/bin/env python3
"""Generate TB-1E Fritzing parts (ESP32 38-pin, CW-022 4CH) and wiring sketch (.fzz)."""

import html
import os
import uuid
import zipfile
from pathlib import Path

ROOT = Path(__file__).resolve().parent
PARTS_DIR = ROOT / "parts"
SVG_DIR = PARTS_DIR / "svg"
OUT_FZZ = ROOT / "TB-1E_ESP32_CW022_Wiring.fzz"

# ESP32 DevKit V1 style 38-pin labels (left column top→bottom, right column top→bottom)
ESP32_LEFT = [
    "3V3", "EN", "VP", "VN", "GPIO34", "GPIO35", "GPIO32", "GPIO33",
    "GPIO25", "GPIO26", "GPIO27", "GPIO14", "GPIO12", "GPIO13", "GND", "VIN",
    "NC1", "NC2", "NC3",
]
ESP32_RIGHT = [
    "GND", "GPIO23", "GPIO22", "TX0", "RX0", "GPIO21", "GPIO19", "GPIO18",
    "GPIO5", "GPIO17", "GPIO16", "GPIO4", "GPIO0", "GPIO2", "GPIO15", "GND",
    "NC4", "NC5", "NC6",
]
ESP32_PINS = ESP32_LEFT + ESP32_RIGHT

CW022_PINS = ["GND", "IN1", "IN2", "IN3", "IN4", "VCC"]

# TB-1E motor relay wiring (ESP32 GPIO name -> CW-022 input)
MOTOR_WIRES = [
    ("VIN", "VCC", "#cc0000"),
    ("GND", "GND", "#000000"),
    ("GPIO26", "IN1", "#3366cc"),
    ("GPIO27", "IN2", "#3366cc"),
    ("GPIO14", "IN3", "#009900"),
]


def pin_id(index: int) -> str:
    return f"connector{index}"


def make_rect_svg(view: str, width: float, height: float, pins, left_side: bool) -> str:
    """Build breadboard/schematic SVG with connector pins."""
    lines = [
        '<?xml version="1.0" encoding="UTF-8" standalone="no"?>',
        f'<svg xmlns="http://www.w3.org/2000/svg" width="{width}in" height="{height}in" '
        f'viewBox="0 0 {width * 100} {height * 100}" id="svg">',
        f'<g id="{view}">',
    ]
    if view == "breadboard":
        lines.append(
            f'<rect x="5" y="5" width="{width*100-10}" height="{height*100-10}" '
            'rx="4" fill="#006600" stroke="#003300" stroke-width="2"/>'
        )
    else:
        lines.append(
            f'<rect x="10" y="10" width="{width*100-20}" height="{height*100-20}" '
            'fill="none" stroke="#000000" stroke-width="2"/>'
        )

    n = len(pins)
    for i, name in enumerate(pins):
        if left_side:
            row = i
            cx, cy = 8, 20 + row * (height * 100 - 40) / max(n - 1, 1)
            tx = 18
        else:
            # right side pins for dual-row parts handled by caller
            row = i
            cx, cy = width * 100 - 8, 20 + row * (height * 100 - 40) / max(n - 1, 1)
            tx = width * 100 - 55

        pin_suffix = "pin" if view == "breadboard" else "pin"
        term_suffix = "terminal" if view == "schematic" else ""
        cid = pin_id(i if left_side else i)

        if view == "breadboard":
            lines.append(
                f'<rect id="{cid}pin" x="{cx-4}" y="{cy-3}" width="8" height="6" '
                f'fill="#cccccc" stroke="#888888"/>'
            )
        else:
            lines.append(f'<circle id="{cid}pin" cx="{cx}" cy="{cy}" r="3" fill="none" stroke="#000"/>')
            lines.append(f'<rect id="{cid}terminal" x="{cx-2}" y="{cy-2}" width="4" height="4" fill="none"/>')

        label = html.escape(name)
        lines.append(
            f'<text x="{tx}" y="{cy+3}" font-size="7" font-family="Arial" fill="#ffffff">{label}</text>'
            if view == "breadboard"
            else f'<text x="{tx}" y="{cy+3}" font-size="7" font-family="Arial">{label}</text>'
        )

    lines.append("</g></svg>")
    return "\n".join(lines)


def make_esp32_breadboard_svg() -> str:
    w, h = 2.6, 4.8
    lines = [
        '<?xml version="1.0" encoding="UTF-8" standalone="no"?>',
        f'<svg xmlns="http://www.w3.org/2000/svg" width="{w}in" height="{h}in" '
        f'viewBox="0 0 {w*100} {h*100}">',
        '<g id="breadboard">',
        f'<rect x="15" y="10" width="{w*100-30}" height="{h*100-20}" rx="6" fill="#00979d" stroke="#004446" stroke-width="2"/>',
        f'<text x="{w*50}" y="28" text-anchor="middle" font-size="10" fill="#fff" font-family="Arial">ESP32 DevKit</text>',
        f'<text x="{w*50}" y="40" text-anchor="middle" font-size="7" fill="#fff" font-family="Arial">38 Pin — TB-1E</text>',
    ]
    n = 19
    for i in range(n):
        y = 55 + i * ((h * 100 - 70) / (n - 1))
        # left pin
        cid_l = pin_id(i)
        lines.append(f'<rect id="{cid_l}pin" x="17" y="{y-3}" width="8" height="6" fill="#ccc" stroke="#888"/>')
        lines.append(f'<text x="28" y="{y+3}" font-size="6" fill="#fff" font-family="Arial">{html.escape(ESP32_LEFT[i])}</text>')
        # right pin
        cid_r = pin_id(i + 19)
        lines.append(f'<rect id="{cid_r}pin" x="{w*100-25}" y="{y-3}" width="8" height="6" fill="#ccc" stroke="#888"/>')
        lines.append(
            f'<text x="{w*100-72}" y="{y+3}" font-size="6" fill="#fff" text-anchor="end" '
            f'font-family="Arial">{html.escape(ESP32_RIGHT[i])}</text>'
        )
    lines.append("</g></svg>")
    return "\n".join(lines)


def make_cw022_breadboard_svg() -> str:
    w, h = 2.0, 1.6
    lines = [
        '<?xml version="1.0" encoding="UTF-8" standalone="no"?>',
        f'<svg xmlns="http://www.w3.org/2000/svg" width="{w}in" height="{h}in" viewBox="0 0 {w*100} {h*100}">',
        '<g id="breadboard">',
        f'<rect x="10" y="10" width="{w*100-20}" height="{h*100-20}" rx="4" fill="#1a1a2e" stroke="#000" stroke-width="2"/>',
        f'<text x="{w*50}" y="28" text-anchor="middle" font-size="9" fill="#fff" font-family="Arial">CW-022</text>',
        f'<text x="{w*50}" y="40" text-anchor="middle" font-size="7" fill="#aaa" font-family="Arial">4CH 5V Relay</text>',
    ]
    for i, name in enumerate(CW022_PINS):
        y = 55 + i * 18
        cid = pin_id(i)
        lines.append(f'<rect id="{cid}pin" x="12" y="{y-3}" width="8" height="6" fill="#ccc" stroke="#888"/>')
        lines.append(f'<text x="24" y="{y+3}" font-size="7" fill="#fff" font-family="Arial">{html.escape(name)}</text>')
    lines.append("</g></svg>")
    return "\n".join(lines)


def make_simple_schematic_svg(title: str, pins) -> str:
    w = 2.5
    h = 0.4 + len(pins) * 0.25
    lines = [
        '<?xml version="1.0" encoding="UTF-8" standalone="no"?>',
        f'<svg xmlns="http://www.w3.org/2000/svg" width="{w}in" height="{h}in" viewBox="0 0 {w*100} {h*100}">',
        '<g id="schematic">',
        f'<text x="50" y="15" font-size="9" font-family="Arial">{html.escape(title)}</text>',
    ]
    for i, name in enumerate(pins):
        y = 25 + i * 20
        cid = pin_id(i)
        lines.append(f'<line x1="10" y1="{y}" x2="30" y2="{y}" stroke="#000"/>')
        lines.append(f'<circle id="{cid}pin" cx="30" cy="{y}" r="3" fill="none" stroke="#000"/>')
        lines.append(f'<rect id="{cid}terminal" x="28" y="{y-2}" width="4" height="4" fill="none"/>')
        lines.append(f'<text x="38" y="{y+3}" font-size="7" font-family="Arial">{html.escape(name)}</text>')
    lines.append("</g></svg>")
    return "\n".join(lines)
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

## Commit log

2026-06-30 Initial commit: TB-1E ESP32 controller with Android, iOS, and web apps
2026-06-30 Improve Web Bluetooth connect errors and device discovery on PC
2026-06-30 Improve BLE connection stability for PC Chrome
    [bt_controller.ino]
2026-07-04 Add Manual/Auto modes, limit switches, ON-HOLD, and auto latch control
2026-08-01 Update AUTO-DOWN, limits, ON-HOLD, and panel control
    [TB-1E_ESP32_CW022_Wiring.fz, TB-1E_ESP32_CW022_Wiring.fzz]
2026-08-05 Add ON-HOLD app indicator, panel-matched BLE control, and AUTO-DOWN fixes.
    ESP32 sends HOLD status, fixes ON-HOLD edge handling for AUTO-DOWN, and mirrors panel button logic for app commands. Web, Android, and iOS show green/red ON-HOLD state with slow beep while processing.
    [bt_controller.ino]
2026-08-05 Move device status panel below control buttons across all apps.
    Relocate mode, ON-HOLD, and auto hint to the bottom-right under XUỐNG while keeping BLE connection status under the connect button. Bump Android to v1.5 and fix DeviceMenu compile params.
2026-08-05 Show mode and function hint below ON-HOLD in device status panel.
    Reorder bottom status to ON-HOLD, then mode label, then mode behavior text for both Manual and Auto across web, Android, and iOS.
2026-08-05 Hide device status hints in web app when disconnected.
    Keep ON-HOLD, mode, and mode function text hidden until BLE is connected; hide desktop keyboard hint until connected as well.
2026-08-05 Remove Windows BLE hint box from web app UI.
    Delete the yellow Windows scan instructions entirely and enforce device-status hidden styling so ON-HOLD does not show when disconnected.
2026-08-05 Force-remove cached Windows BLE hint from web app v1.6.
    Add cache-busting query params, CSS kill-switch for legacy ble-hint, and DOM cleanup on load so stale cached pages no longer show the yellow Windows box when connected.
2026-08-05 Move ON-HOLD status onto machine panel with larger label.
    Overlay device status on the machine illustration face across web, Android, and iOS; show mode and function in smaller text below ON-HOLD when connected. Web v1.7.
2026-08-05 Document ASCII-only project path for Windows tooling.
    Rename folder references from Vietnamese Unicode paths to Gia-cong/drawings/safety-belt-tester so Gradle and Fritzing work reliably.
2026-08-05 Move ON-HOLD up 10px without shifting mode lines (v1.7.15).
    Pin mode text at a fixed vertical position and overlay processing on its own line.
